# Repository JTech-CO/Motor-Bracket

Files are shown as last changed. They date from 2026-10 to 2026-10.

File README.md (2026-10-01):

# 스마트카트 모터 브래킷 · Rev G / 0.7.0

학교 프린터의 **200 × 200 × 200 mm** 상한에 맞춘 폭 축소 개정. 본체는 **196 × 162 × 180 mm**, 좌우 각각 별도의 단일 솔리드이며 분할 접합 없이 한 개씩 출력함.

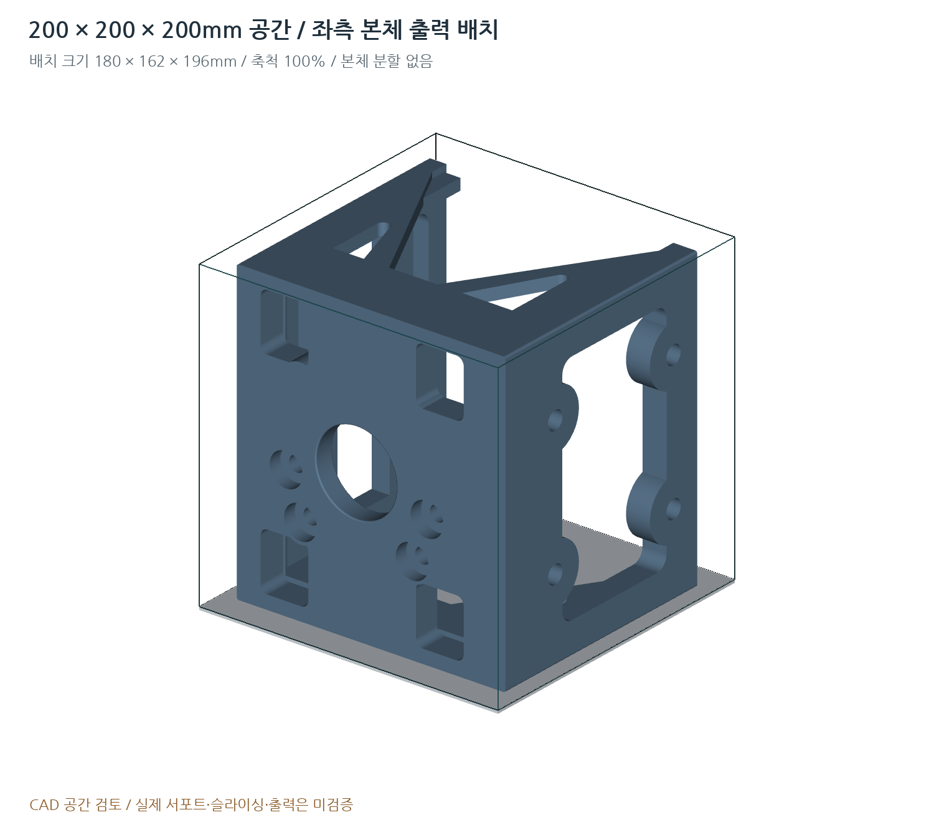
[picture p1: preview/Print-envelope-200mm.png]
200mm 출력 공간


## 우선 사용할 파일

- 출력: `print/bed_ready/SCMB-G01-L-BED.stl`, `SCMB-G01-R-BED.stl` — 각각 1개. 배치 크기 **180 × 162 × 196 mm**.
- 받침: 같은 폴더의 `SCMB-G03-L-BED.stl`, `SCMB-G03-R-BED.stl` — 각각 1개. **176 × 105 × 41.430 mm**.
- SolidWorks: `cad/step/SCMB-G01-L.step` / `SCMB-G01-R.step`. 받침은 G03, 금속 참고부 포함 조립은 G10.
- FreeCAD: `cad/freecad/`의 같은 이름 FCStd. 빈 화면이면 루트 `OPEN_IN_FREECAD.FCMacro`로 BREP를 직접 가져와 네이티브 재저장.
- 도면: [설계도면](drawings/설계도면.pdf), [수정설명서](docs/수정설명서.pdf), 1:1 모터/차체 템플릿.

## Rev F 대비 변경

| 항목 | Rev F | Rev G |
|---|---:|---:|
| 본체 크기 | 212 × 162 × 180 | **196 × 162 × 180 mm** |
| 외곽 좌우 끝 | ±106 | ±98 mm |
| 상·하판 경량화 창 폭 | 170 | 154 mm |
| 전면 창의 좌우 중심 | ±78 | ±70 mm |
| 받침 레일 바깥/안쪽 좌표 | ±96 / ±84 | ±88 / ±76 mm |
| 핀 중심 X | ±90 | ±82 mm |
| 전방 모서리 기둥 깊이 | 30 | 28 mm |

단순 전체 축소를 하지 않음. 상판 M8×40 4개, 측면 M6×30 4개, 차체 중심간격90×100, 출력축 위치, 모터 각도L -45° / R135°, 8인치 기준 명목 지상고21.6 mm를 유지함. 상판16 / 측판18 / 하판12 / 거싯8 mm와 루트R10도 유지함.

## 출력 공간

회전 배치 STL의 본체 영역은 X10~190 / Y19~181 / Z0~196 mm. 200 mm 배드 중심에 한 부품씩 배치함. 5 mm 외곽 브림을 가정한 공간은 **190 × 172 mm**, 높이는196 mm임. 이는 기하학적 영역 계산이며 실제 서포트·퍼지라인·스커트·래프트·툴패스 검증이 아님. 외부 서포트가 이를 넘을 수 있으므로 학교 슬라이서 프로필에서 확인함. 래프트/두꺼운 받침을 추가하면 Z=200 mm 제한을 다시 확인함.

**100% 크기(mm) / 사용자가 요청한 100% 채움 설정.** STL에는 채움률이 저장되지 않음. 축소하여 맞춤 기능은 사용하지 않음. 기본 방향 STL도 최대196 mm라 200 mm 큐브 안에 들어가지만, 배드 회전본은 X/Y에 브림 여유를 더 확보한 배치임. 층간하중과 서포트는 실제 재료·출력 방향으로 재검토해야 함.

## 질량과 기하 검사

기존 밀도1.06 g/cm³ 입력을 유지한 CAD 계산: 본체 **1.193 kg/개**, 받침 **0.113 kg/개**, 플라스틱 좌우 합계 **2.611 kg**. 금속부·모터·서포트·브림은 제외함. Rev F 약2.800 kg 대비 약0.189 kg 감소함.

대리 모터 캔과 본체의 최소 기하 간격 **1.699 mm**. 조립 및 연속200 mm 삽입 경로 검사 **165개**, 출력공간·고정치수·실제홀축 검사 **68개** 통과. 모든 출력용 본체/받침의 STEP·STL 최대 치수를 검사함. 결과는 `qa/`에 있음.

**DEMO 형상 무간섭이 실물 맞춤이나 하중 안전을 보장하지 않음.** 모터 자료5쪽의 D01 외경·E02 편심·L04 보스·M01 귀 두께 등은 실측 대기 상태임. 외곽 폭을 줄여 주변 여유가 작아졌으므로 실측 대조가 특히 중요함. 21.6 mm 지상고는 타이어 눌림·구조 변형·바닥 요철을 차감하기 전의 명목값임.

## CAD 및 구조 검증의 한계

FCStd는 외부에서 직렬화한 `Part::Feature` 정밀 솔리드. 완전 구속 스케치·피처 이력은 아님. 형상 입력 치수의 재생성 원본은 `parameters.json`과 `src/geometry.py`임. `.SLDPRT`/`.SLDASM`/Simulation 프로젝트를 생성하지 않음. STEP는 정밀 솔리드 가져오기/직접 편집의 시작 형상임.

FreeCAD·SolidWorks 앱의 실제 화면/열기 검사는 미실시. 기존 BREP 직접 가져오기 매크로와 AP214 대안을 유지함. 매크로 역시 문법 검사만 실시함. **Rev G 구조 FEA·실물 출력·하중시험 미실시.** 단면/레일 위치 변경으로 기존 개정의 응력·변위·안전율을 전용하지 않음.

## 재생성

```bash
python -m pip install -r requirements.txt
python src/export_package.py
python src/check_design.py
python src/check_print_envelope.py
python src/render_preview.py
python src/render_print_bed.py
python src/write_docs.py
python src/make_drawings.py
python src/verify_package.py
python src/finalize_package.py
```

문서 생성에는 로컬 한국어 TTF가 필요함. Windows 맑은 고딕/리눅스 나눔고딕 또는 `FONT_KR`·`FONT_KR_BOLD` 환경변수를 사용함. 폰트 파일은 배포하지 않음. 치수를 바꾸면 구형 생성파일을 혼용하지 않고 전체 재생성함. 내보내기는200 mm 초과 시 중단함.

참조PDF2개·PNG1개는 `reference/`에 원본 유지. 자료에서 확정되지 않은 길이를 추측해 실측값으로 바꾸지 않음. 기준 저장소 커밋: `4792da580a78f302c24412488b0d653e7083863d` (Rev F). 원격 GitHub는 이 패키지로 수정하지 않았음.

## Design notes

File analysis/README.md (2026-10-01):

# 구조해석 상태

Rev G(196 × 162 × 180 mm)는 구조 FEA 미실시임. Rev E의 수치 및 Rev F의 형상 검사를 본 개정의 안전율이나 강도 승인으로 사용하지 않음.

상판 16 / 측판 18 / 하판 12 / 거싯 8 / 루트 R10은 유지함. 폭, 전면 창 위치, 측면 기둥 깊이, 레일과 잠금핀 위치를 변경했으므로 실제 접촉·적층 이방성·볼트 예압·크리프·열 조건을 넣어 새 형상으로 재해석해야 함.

해석용 시작 형상은 cad/step/SCMB-G10-L.step 및 R.step의 분리 솔리드 조립임. 모터 대리형상은 제작 대상이 아니며 모터 본체의 질량/출력축 하중 조건을 별도로 설정함. `src/geometry.py`의 bonded_analysis는 완전결합 비교체를 만드는 함수로 실제 접촉모형을 대체하지 않음.

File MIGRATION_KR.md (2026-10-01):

# Rev F → Rev G 교체 안내

원격 저장소의 .git 디렉터리와 사용자 변경을 보존하고 별도 브랜치 또는 백업에서 교체함. 자동 삭제·git push는 이 패키지에서 실행하지 않음.

이 패키지는 전체 생성본임. 이전 `cad/`, `compatibility/`, `drawings/`, `print/`, `preview/`, `qa/`의 Rev F 출력 파일은 새 파일과 함께 발주/출력 목록에 남기지 않음. Git의 변경 목록에서 `SCMB-F*`가 제거되고 `SCMB-G*`로 바뀌는지 검토함. `parameters.json`, `src/`, 루트 매크로/안내/검사파일과 data/도 함께 교체함.

각 본체 폭196 mm, 각 받침 폭176 mm. 체결용 M8·M6의 수와 길이 및 차체 피치는 같지만 레일과 핀 위치가8 mm 이동했으므로 **Rev F 받침과 Rev G 본체를 혼합하지 않음**. 좌우 표기도 유지함. 모터·바퀴가 포함된 검토 조립 STEP는 출력 대상이 아님.

배포 후 `python CHECK_FILES.py`로 로컬 파일 손상 여부를 점검함. 이는 실제 CAD 앱 화면 검사와 별개임.

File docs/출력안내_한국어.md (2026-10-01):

# 200 mm 프린터 출력 안내

`print/bed_ready`의 L/R 본체 및 L/R 받침을 각각1개씩, 한 번에 한 부품으로 출력함. 본체 BED STL은 측면을 아래로 회전 배치하여180×162×196 mm임. 바닥 좌표는Z=0이며 mm/축척100%를 사용함. 원본 방향 STL은196×162×180 mm임.

명목200 mm 큐브 안에 들어가는 형상 검사를 완료했으나 기종·노즐·재료 설정이 미제공이라 실제 슬라이싱은 미실시임. 5 mm 브림을 더한 본체 외접영역190×172 mm는 계산 예시이며 실제 접착력 보장이나 권장 브림 폭 확정이 아님. 서포트, 스커트, 퍼지, 클립, 래프트의 최종 툴패스를 포함해200 mm를 넘는지 확인함. 최종Z높이도200 mm 이하여야 함.

100% 채움은 슬라이서에서 지정함. 출력품의 물성은 적층방향과 실제 공정에 달려 있으므로 100% 채움만으로 강도 승인이 되지 않음. 학교장비가 선택한재료에 필요한 노즐·챔버·건조 조건을 제공하는지 확인함. 끼워맞춤·홀·레일은 작은 시험편 또는 해당 단면 선행 출력으로 보정 후 본체를 출력함.

M8용 금속 압축제한슬리브와 M6용 금속 압축제한슬리브, 잠금핀은 플라스틱으로 대체 출력하지 않음. reference나 모터대리형상은 제작대상이 아님. 모터 맞춤은 실측해야하며 체결 토크와 실물 운행 하중은 아직 승인하지 않음.

외부 참고: Prusa의 Skirt and Brim 문서는 브림이 첫 레이어 접착면적을 늘리며 폭을 별도로 설정하는 기능임을 설명함. 특정 학교 장비에 대한 프로필은 아님. https://help.prusa3d.com/article/skirt-and-brim_133969

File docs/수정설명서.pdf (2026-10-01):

SCMB Rev G / 200mm 공간 검토본 / 실물·구조 승인 전 | 1

# Rev G / 200mm 프린터 대응 수정

스마트카트 모터 브래킷 · 0.7.0 · 2026-10-01
좌우 단일 본체196×162×180mm / 기능 치수 유지 / 제작 검토본

### 1. 전체 비율이 아닌 외곽 폭만 줄임

학교 프린터 상한200×200×200mm를 기준으로 외곽 폭212mm를196mm로 조정했다. 각 본체를 별도 파트로 분할하지 않는다. 전체 모델을196/212 비율로 축소하지 않고 측면 구조와 경량화 창·받침 레일을 국소적으로 이동했다.

항목 | Rev F | Rev G
본체 외곽(mm) | 212×162×180 | 196×162×180
레일 전체 폭(mm) | 192 | 176
핀 중심X(mm) | ±90 | ±82
상·하판 창 폭(mm) | 170 | 154
전방 기둥 깊이(mm) | 30 | 28

상판16 / 측판18 / 하판12 / 거싯8mm와 루트R10을 유지했다. 앞쪽 기둥 두께12mm도 유지하고 깊이를 2mm 줄여 대리 모터의 Y=30 앞끝과의 공간을 확보했다. 이번 국소 변경이 강도 유지의 검증을 의미하지 는 않는다.

기존 밀도1.06g/cm³를 그대로 사용한 CAD 플라스틱 질량은 좌우 합계 2.611kg이다. Rev F 약2.800kg 대비 약0.189kg 감소했다. 모터·금속부·서포트·브림·출력 오차를 제외한다.

기준 저장소: JTech-CO/Motor-Bracket, 커밋4792da580a78f302c24412488b0d653e7083863d의 Rev F. geometry.py의 Git blob SHA를 대조한 후 소스를 수정했다. 원격 저장소 수정이나 발주는 하지 않 았다.

# 2. 출력 배치와 슬라이서 설정

출력 파일 | 배치 크기(mm) | 수량
SCMB-G01-L-BED.stl | 180×162×196 | 1
SCMB-G01-R-BED.stl | 180×162×196 | 1
SCMB-G03-L-BED.stl | 176×105×41.430 | 1
SCMB-G03-R-BED.stl | 176×105×41.430 | 1

print/bed_ready의 본체 파일은 측면을 바닥으로 +Y축90° 회전하고 XY 중앙·Z0으로 옮긴 STL이다. 축척 은100%이며 스케일 변경이 아니다. 원래 방향 STL도196×162×180mm로200mm 큐브 안에 들어간다.

본체 배치 좌표는 X10~190 / Y19~181 / Z0~196mm이다. 5mm 브림을 가정하면 외접영역은 190×172mm이고 높이는196mm로 유지된다. 이는 브림의 기하 공간 계산이며 학교 장비의 실제 G-code 는 생성하지 않았다.

### 실제 출력 전에 확인

한 작업에 본체 한 개씩 배치하고 mm·축척100%·내부채움100%를 사용한다. STL에는 채움률이 저장되 지 않는다. 받침은 별도 작업이다. 모터·바퀴·금속부가 들어간 검토조립 STEP는 출력대상이 아니다.

슬라이서에서 서포트·브림·스커트·퍼지·래프트를 포함한 최종 툴패스가200mm 공간 안인지 확인한다. 학 교 기종·클립 위치·제한구역·노즐·재료 프로필이 없어 실제 슬라이싱은 미검증이다. 래프트나 높이 보정을 추가하면 남은Z여유4mm를 초과하지 않는지 확인한다.

측면 출력 방향은 공간 적합성을 위한 배치다. 층간강도와 서포트 접촉을 검토한 출력조건을 사용한다. 5mm 브림을 접착력 확정값으로 취급하지 않는다. 장비가 재료의 건조·노즐·챔버 조건을 충족하는지도 확 인한다.

브림 참고: Prusa 공식 “Skirt and Brim”은 첫 레이어의 접착면적을 늘리며 폭을 따로 지정하는 기능으로 설 명한다. 이 설명은 학교 프린터 전용 설정을 제공하는 것은 아니다. 주소는data/sources.json에 있다.

# 3. 바퀴·체결 및 CAD 파일

유지 항목 | Rev G 값
차체 체결 | M8×40mm 4개 / 중심 간격90×100mm
모터 체결 | M6×30mm 4개 / 원본 공급원 패턴의 회전 좌표 유지
출력축 중심 | 좌우 동일 높이Z0 / 중앙 여유홀Ø54와 동심
하판 최하단 / 상판면 | Z=-80 / Z=+100mm
8인치 명목 지상고 | 203.2/2 - 80 = 21.6mm
모터 상대 각도 | L -45° / R135° / 차이180°

Ø54 개구는 축을 지지하는 베어링홀이 아니다. 바퀴허브·모터베어링 하중과 축물림은 별도 확인해야 한다. 21.6mm는 무하중 명목값으로 타이어 눌림과 구조 변형이 차감되기 전이다.

브래킷 M8/M6 자리는 각각 Ø12.2/Ø10.2 슬리브 수용홀이다. 금속 슬리브 ID는Ø9.0/Ø6.6이다. 볼트 유 효 두께12/9mm를 유지했으나 모터 귀와 잠금너트·와셔 실측이 없으므로 M6×30의 길이 적합성과 체결토 크는 확정 전이다.

### FreeCAD와 SolidWorks

cad/step은 각각 유효한 단일 솔리드 AP203을 제공한다. 대안 AP214는compatibility/AP214에 있다. SolidWorks는STEP를 가져와 직접 편집하거나 새 피처/해석을 추가하는 시작형상으로 사용한다. 고유 SLDPRT/SLDASM/Simulation 프로젝트는 제공하지 않는다.

cad/freecad의 FCStd는 외부 직렬화한 Part::Feature 솔리드 문서이며 원시 스케치 이력이 아니다. 빈 화 면이면 OPEN_IN_FREECAD.FCMacro로BREP를 직접 읽어 표시·네이티브 저장·재열기를 수행한다. 실제 앱 버전/결과는native_generated/app_report.json에 기록된다. 여기서는 앱/매크로 실행은 하지 않았다.

parameters.json·src/geometry.py가 재생성 원본이다. 전용 출력 한계 검사로200mm 초과 시 내보내기 를 중단한다. 기존Rev F 본체/받침과 새Rev G를 혼용하지 않는다.

# 4. 검증 결과와 제작 승인 조건

검사 항목 | 실행 결과
기하·연속200mm 삽입 경로 | 165개 통과 / 명시된 대리형상 기준
출력공간·실제 홀축·회전배치 | 68개 통과 / STEP·STL200mm 이내
STEP / FCStd | AP203·AP214 재읽기 / FCStd ZIP·XML·내장BREP 검사
학교 장비 슬라이싱·출력 | 미실시 / 실제 프로필·툴패스 미제공
CAD 앱 직접 실행 | FreeCAD·SolidWorks 및 매크로 실행 미실시
새 형상 구조해석·하중시험 | 미실시 / 기존 개정의 응력·안전율 전용 금지

모터 캔 대리형상과 본체의 최소 거리는 약1.699mm다. 실제 모터 크기·도장·편심·배선이 다르면 달라진다. 0체적 간섭 및 양의 공차 여유는 실물 끼워맞춤 승인이 아니다.

첨부 모터자료의 5쪽은 D01 몸통 외경, E02 편심, L04 보스, M01 귀 두께와 접촉평면 등을 실측란으로 남 긴다. 공급원Ø102·Ø17과4개 장착홀 좌표는 실측 공차 승인값이 아니다. 본 개정에서 외부 모터치수를 임 의로 확정하지 않았다.

지지대 두께는 유지했지만 폭·레일·보강기둥 위치를 바꾸었으므로 구조 검증은 새 형상으로 수행한다. 실제 접촉, 적층이방성, 볼트 예압, 금속 슬리브, 크리프와 온도를 고려한다. 사람 탑승이나 고속 운행에 대한 승 인을 포함하지 않는다.

참조PDF2개 및PNG1개는 reference/에 원본 그대로 보존했다. 다운로드 무결성은CHECK_FILES.py로 점 검한다. 수치 결과는qa/와data/print_parts.csv에서 볼 수 있다. 한국어 README에 전체 재생성 순서가 있다.

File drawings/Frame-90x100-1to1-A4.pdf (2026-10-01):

# 차체 90×100mm / 홀 중심 대조 1:1

SCMB / Rev G · 0.7.0 / 2026-10-01 / mm / 장착·구조·앱별 최종 승인 전

검토용 · 도면의 미실측 대리값을 제조 확정값으로 사용하지 말 것 | 1 / 1

90mm

100mm

실선 Ø12.2: 상판 슬리브 수용홀 / 점선 Ø24: 와셔 외경 예시. 실제 차체 장공의 최종 볼트 착좌점을 대조한다. 본체196×162mm 외곽은 이 홀 중심 대조도에 표시하지 않는다.

100mm 출력 교정선

인쇄 100% · 페이지 맞춤 끄기 · 교정선을 실제 자로 확인

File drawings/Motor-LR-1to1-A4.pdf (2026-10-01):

# L / 모터 홀 중심 대조용 1:1

SCMB / Rev G · 0.7.0 / 2026-10-01 / mm / 장착·구조·앱별 최종 승인 전

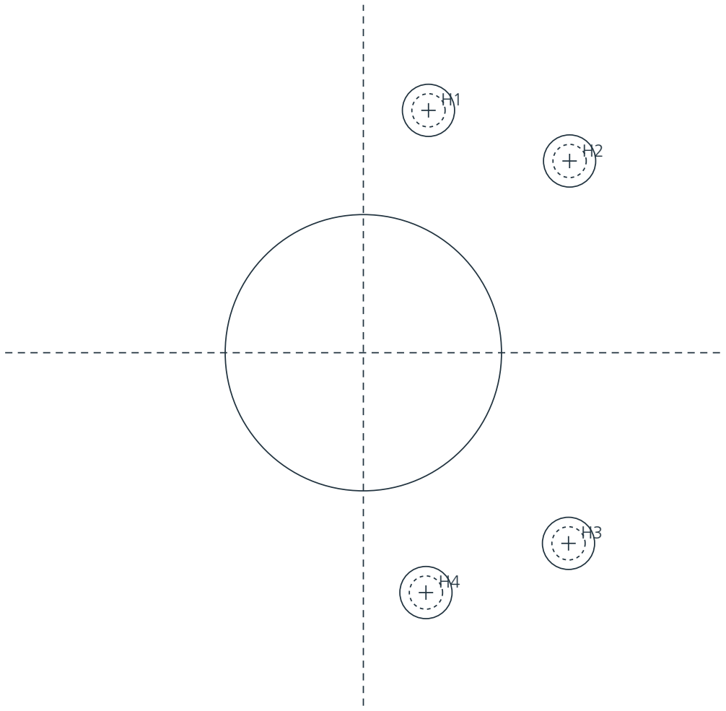
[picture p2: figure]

검토용 · 도면의 미실측 대리값을 제조 확정값으로 사용하지 말 것 | 1 / 2

실선 Ø10.2: 브래킷 슬리브 수용홀 / 점선 Ø6.5: 공급원 모터 귀 구멍. 현재 각도는 대리 편심 기준이다. 실제 모 터에 맞추어 회전/접촉면을 먼저 대조한다.

100mm 출력 교정선

인쇄 100% · 페이지 맞춤 끄기 · 교정선을 실제 자로 확인

# R / 모터 홀 중심 대조용 1:1

SCMB / Rev G · 0.7.0 / 2026-10-01 / mm / 장착·구조·앱별 최종 승인 전

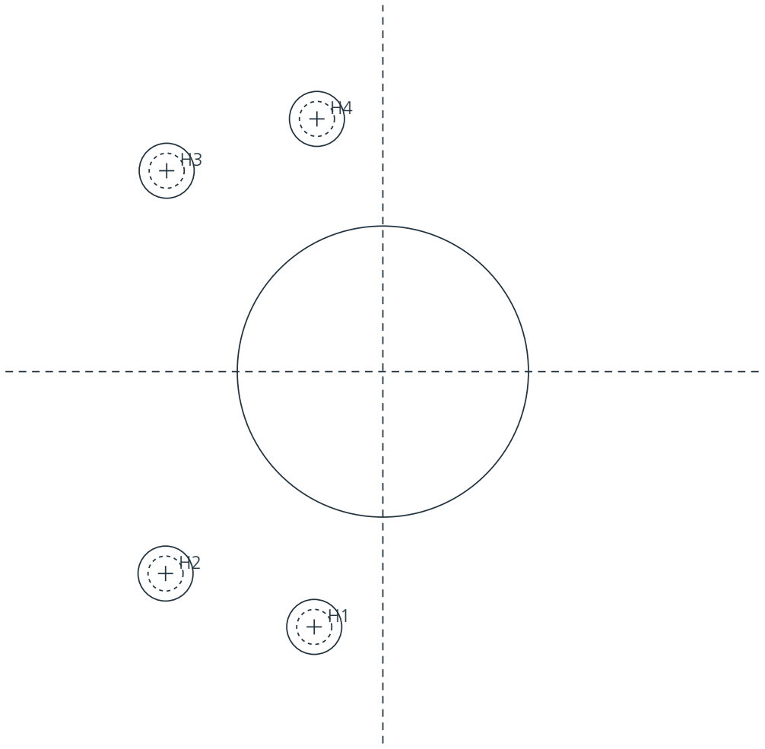
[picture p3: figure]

검토용 · 도면의 미실측 대리값을 제조 확정값으로 사용하지 말 것 | 2 / 2

실선 Ø10.2: 브래킷 슬리브 수용홀 / 점선 Ø6.5: 공급원 모터 귀 구멍. 현재 각도는 대리 편심 기준이다. 실제 모 터에 맞추어 회전/접촉면을 먼저 대조한다.

100mm 출력 교정선

인쇄 100% · 페이지 맞춤 끄기 · 교정선을 실제 자로 확인

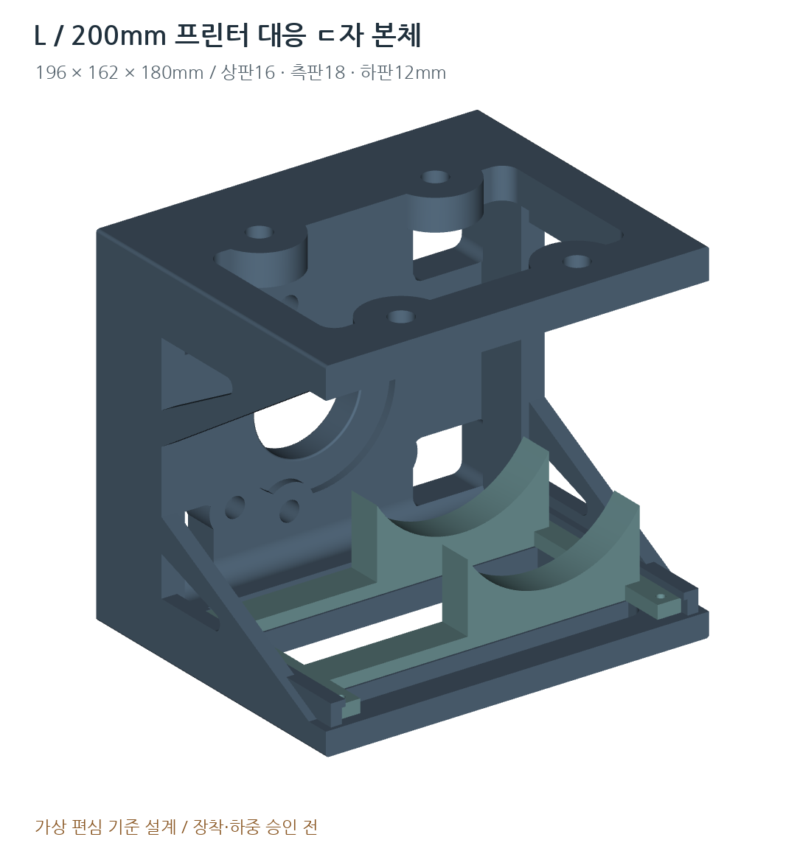
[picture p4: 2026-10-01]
preview/L-Bracket.png

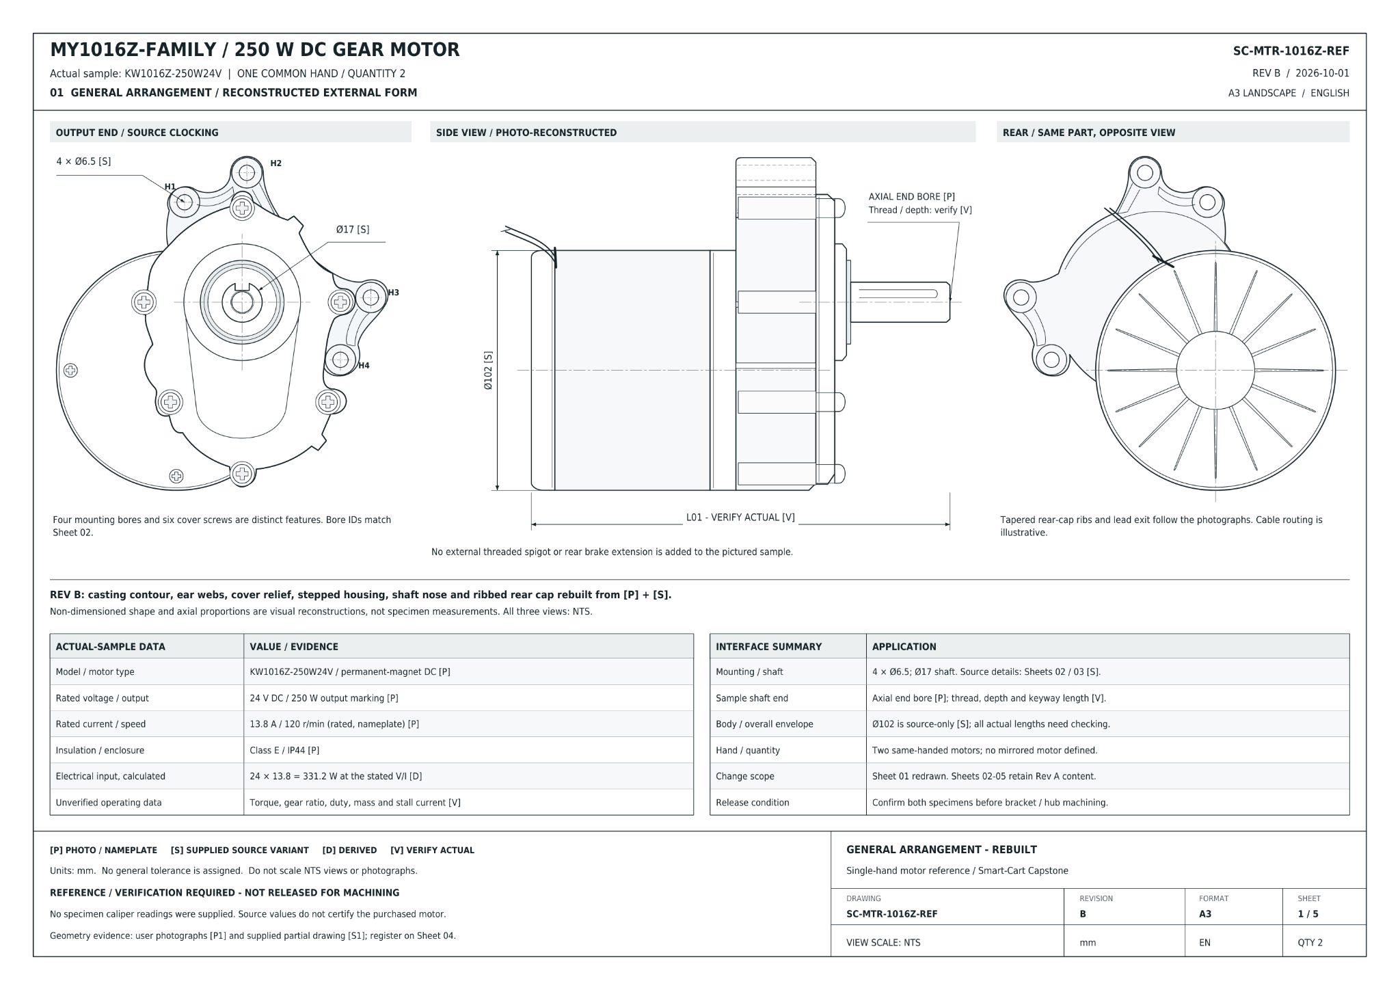
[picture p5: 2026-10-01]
reference/MY1016Z Detailed Reference Image.png

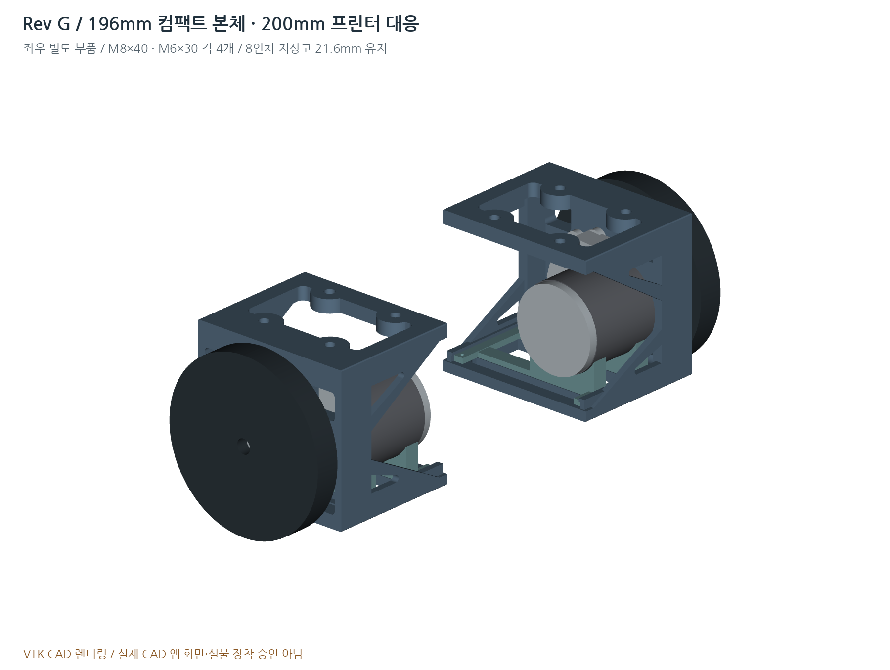
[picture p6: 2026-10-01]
preview/SCMB-RevG-8inch.png

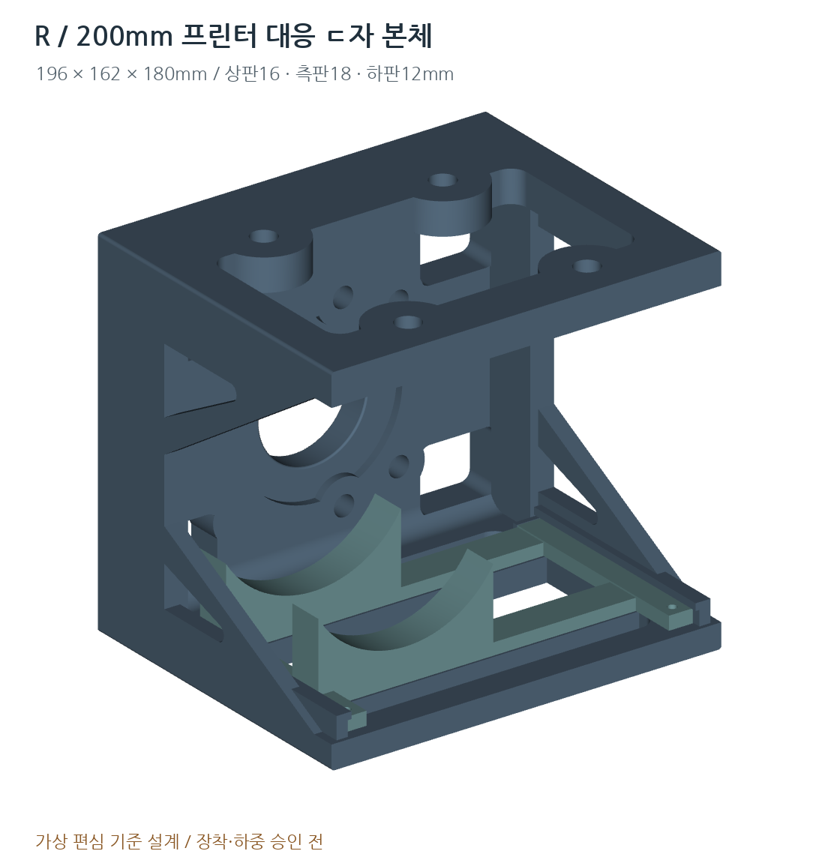
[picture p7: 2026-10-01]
preview/R-Bracket.png

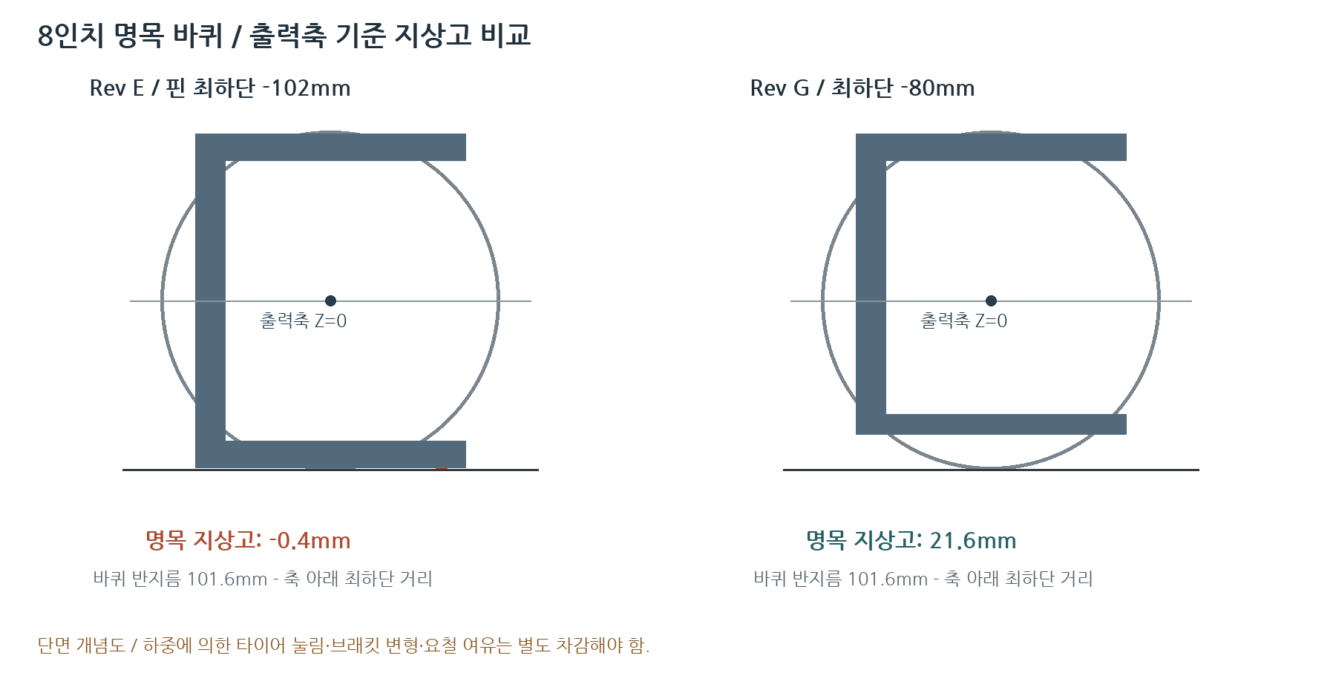
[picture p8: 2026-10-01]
preview/Ground-clearance.png

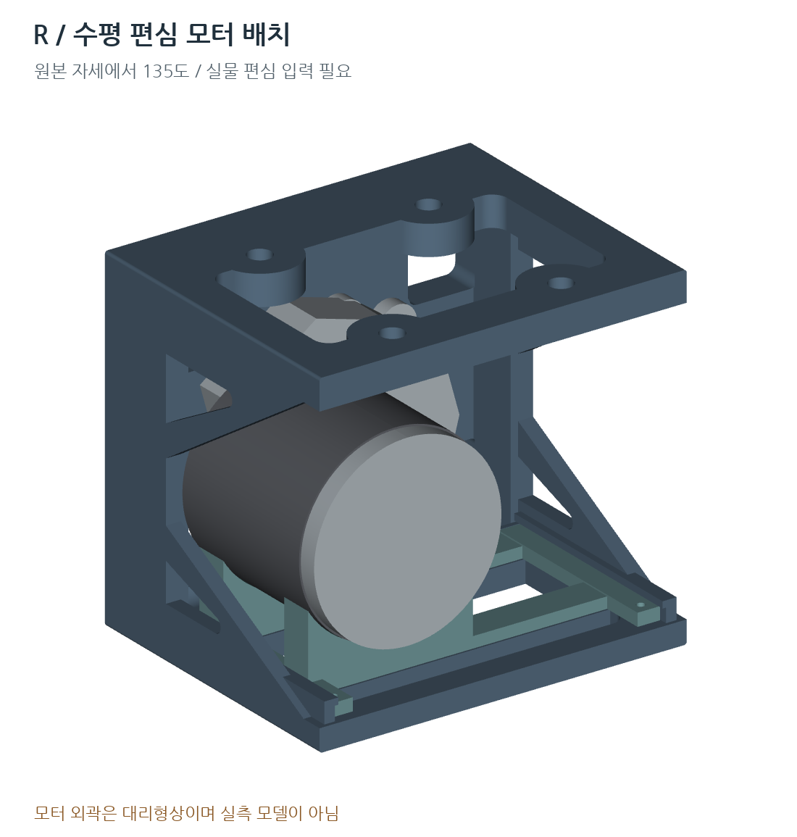
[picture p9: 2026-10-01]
preview/R-Motor.png

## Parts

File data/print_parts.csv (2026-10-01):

부품 | STL파일 | 출력배치Xmm | 출력배치Ymm | 출력배치Zmm | 수량 | 축척 | 채움요청% | 주의
SCMB-G01-L | print/bed_ready/SCMB-G01-L-BED.stl | 180.0 | 162.0 | 196.0 | 1 | 100% | 100 | 한 부품씩 출력 / 서포트·프린터프로필 검토
SCMB-G03-L | print/bed_ready/SCMB-G03-L-BED.stl | 176.0 | 105.0 | 41.43 | 1 | 100% | 100 | 한 부품씩 출력 / 서포트·프린터프로필 검토
SCMB-G01-R | print/bed_ready/SCMB-G01-R-BED.stl | 180.0 | 162.0 | 196.0 | 1 | 100% | 100 | 한 부품씩 출력 / 서포트·프린터프로필 검토
SCMB-G03-R | print/bed_ready/SCMB-G03-R-BED.stl | 176.0 | 105.0 | 41.43 | 1 | 100% | 100 | 한 부품씩 출력 / 서포트·프린터프로필 검토

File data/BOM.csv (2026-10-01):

부품 | 규격 | 양쪽합계 | 상태
좌측 본체 | SCMB-G01-L | 1 | 실측 및 구조 검증 전
우측 본체 | SCMB-G01-R | 1 | 실측 및 구조 검증 전
좌측 받침 | SCMB-G03-L | 1 | 실측 및 구조 검증 전
우측 받침 | SCMB-G03-R | 1 | 실측 및 구조 검증 전
차체 볼트 | M8x40 | 8 | 사용자 규격 / 피치·등급 확인
모터 볼트 | M6x30 | 8 | 사용자 규격 / 귀 두께로 길이 확인
M8 슬리브 | OD12 / ID9 / L11.9 예시 | 8 | 금속 / 실제 길이 확정 전
M6 슬리브 | OD10 / ID6.6 / L8.9 예시 | 8 | 금속 / 실제 길이 확정 전
M8 와셔 | OD24 / t2 예시 | 16 | 차체 장공 받침 검토
M6 와셔 | OD18 / t1.6 예시 | 16 | 모터 접근 검토
M8 잠금너트 | 실제 높이 확인 | 8 | 공급품 확인
M6 잠금너트 | 실제 높이 확인 | 8 | 공급품 확인
금속 잠금핀 | D4 / L24 / 머리2 예시 | 4 | 공급품 규격과 R클립 확인
핀 이탈방지 클립 | 잠금핀에 적합 | 4 | 공급품 확인

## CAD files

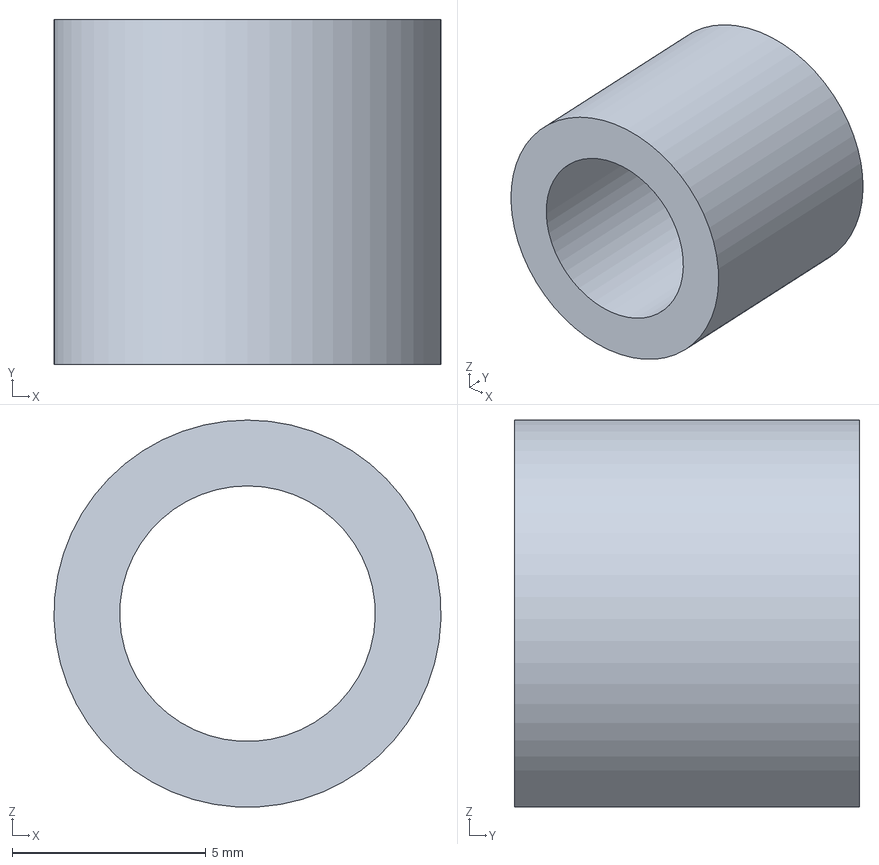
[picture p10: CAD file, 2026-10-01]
cad/step/SCMB-G02-M6.step
10.00 x 8.90 x 9.99 mm

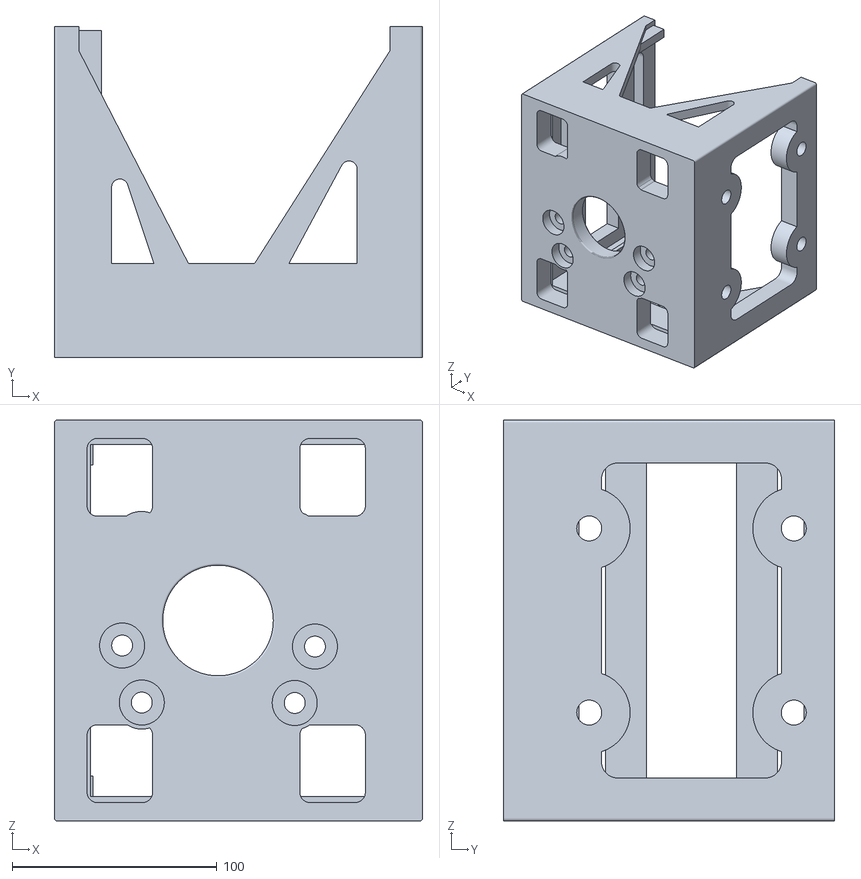
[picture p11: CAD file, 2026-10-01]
print/bed_ready/SCMB-G01-L-BED.stl
180.0 x 162.0 x 196.0

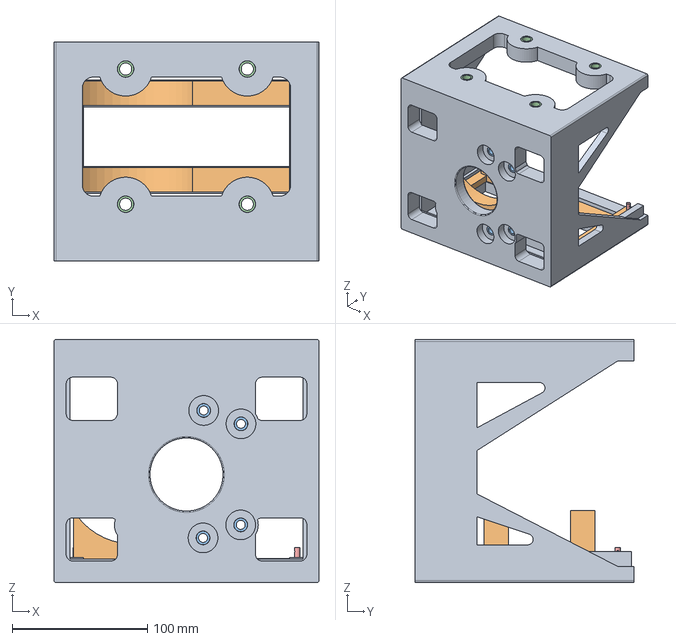
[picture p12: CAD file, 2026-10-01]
cad/step/SCMB-G10-L.step
196.0 x 162.0 x 180.0 mm

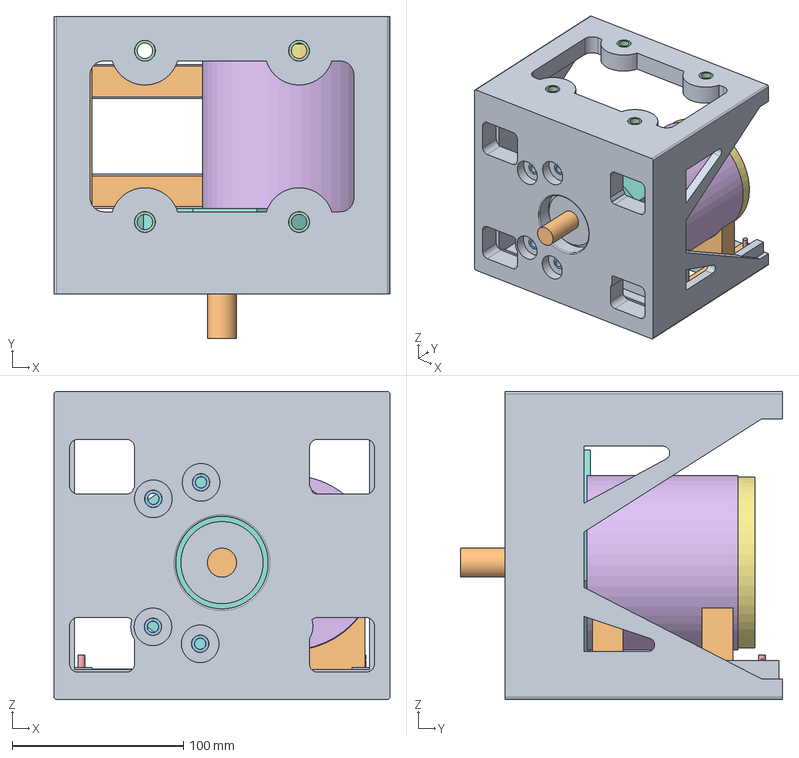
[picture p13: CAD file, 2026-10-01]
compatibility/AP214/SCMB-G20-R-MOTOR-DEMO.step
196.0 x 188.0 x 180.0 mm

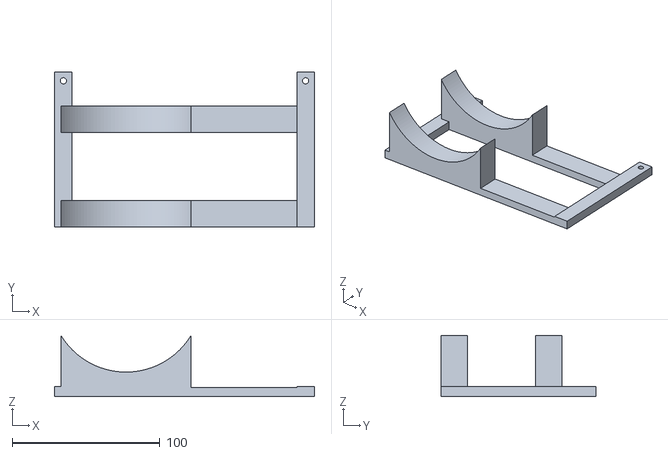
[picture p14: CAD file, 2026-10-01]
print/bed_ready/SCMB-G03-L-BED.stl
176.0 x 105.0 x 41.4

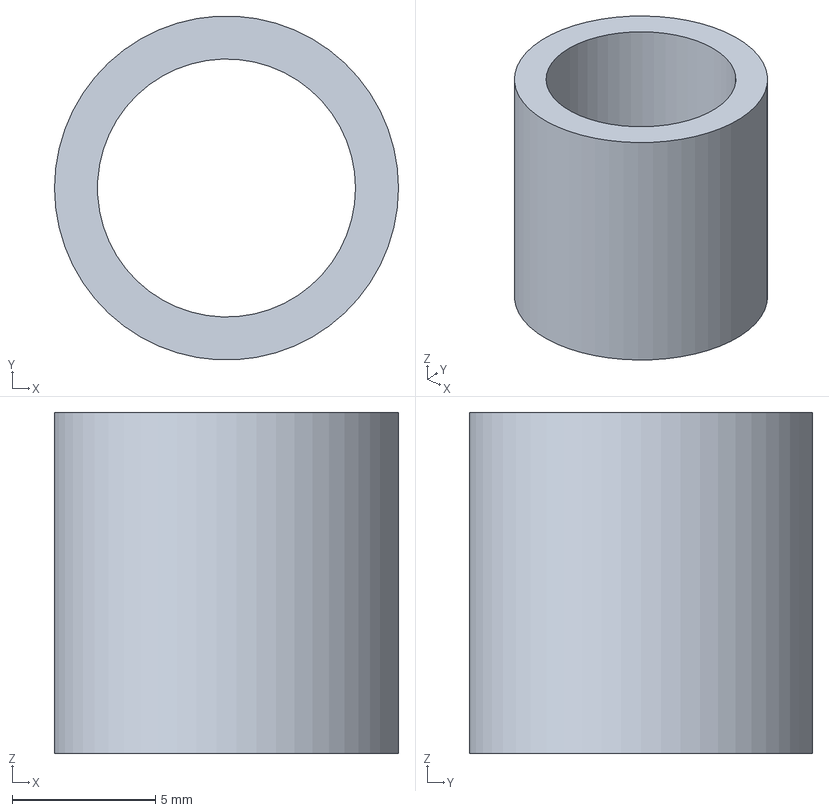
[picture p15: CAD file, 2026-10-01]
compatibility/AP214/SCMB-G02-M8.step
12.0 x 12.0 x 11.9 mm

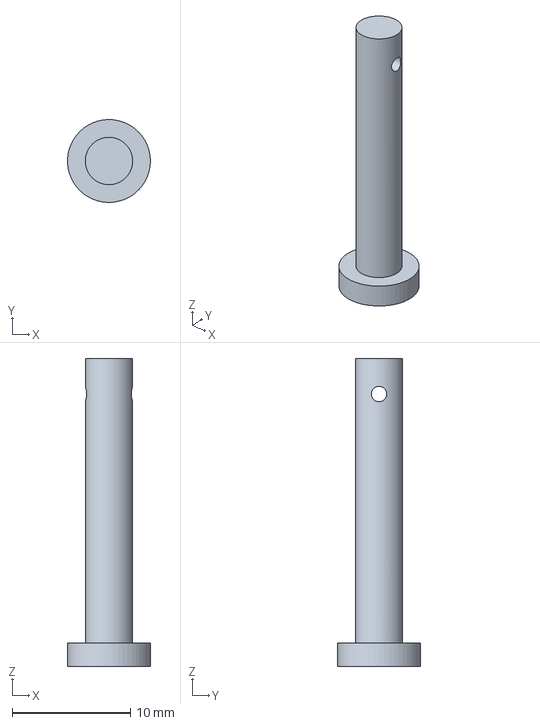
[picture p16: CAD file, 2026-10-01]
cad/step/SCMB-G05-PIN.step
6.99 x 7.00 x 26.0 mm

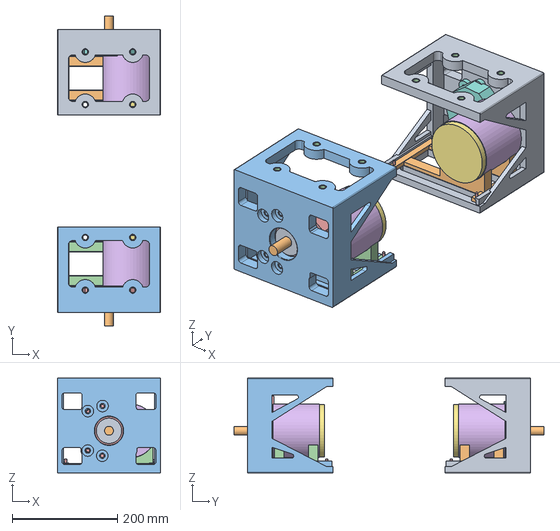
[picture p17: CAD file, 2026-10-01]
compatibility/AP214/SCMB-G00-PAIR-DEMO.step
196.0 x 588.0 x 180.0 mm

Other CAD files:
compatibility/AP214/SCMB-G02-M6.step
cad/step/SCMB-G20-L-MOTOR-DEMO.step
print/bed_ready/SCMB-G01-R-BED.stl
print/bed_ready/SCMB-G03-R-BED.stl
cad/step/SCMB-G10-R.step
compatibility/AP214/SCMB-G03-L.step
cad/step/SCMB-G03-R.step
compatibility/AP214/SCMB-G05-PIN.step
cad/step/SCMB-G00-PAIR-DEMO.step
compatibility/AP214/SCMB-G01-L.step
cad/freecad/00-CAD-TEST-CUBE.FCStd
cad/freecad/SCMB-G00-PAIR-DEMO.FCStd
cad/freecad/SCMB-G01-L.FCStd
cad/freecad/SCMB-G01-R.FCStd
cad/freecad/SCMB-G02-M6.FCStd
cad/freecad/SCMB-G02-M8.FCStd
cad/freecad/SCMB-G03-L.FCStd
cad/freecad/SCMB-G03-R.FCStd
cad/freecad/SCMB-G05-PIN.FCStd
cad/freecad/SCMB-G10-L.FCStd
cad/freecad/SCMB-G10-R.FCStd
cad/freecad/SCMB-G20-L-MOTOR-DEMO.FCStd
cad/freecad/SCMB-G20-R-MOTOR-DEMO.FCStd
cad/step/00-CAD-TEST-CUBE.step
cad/step/SCMB-G01-L.step
cad/step/SCMB-G01-R.step
cad/step/SCMB-G02-M8.step
cad/step/SCMB-G03-L.step
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

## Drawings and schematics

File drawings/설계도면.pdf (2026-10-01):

# 01 / 좌우 단일 본체 · 200mm 프린터 대응

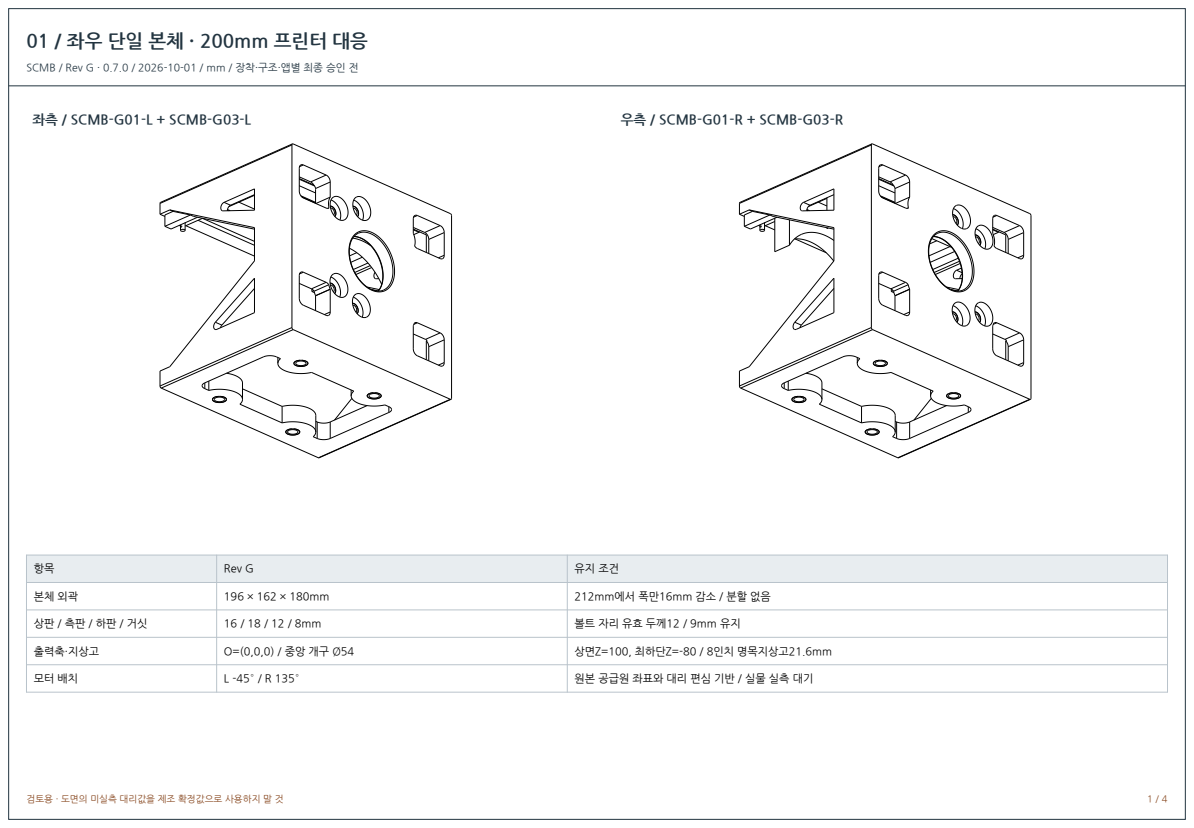
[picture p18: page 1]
검토용 · 도면의 미실측 대리값을 제조 확정값으로 사용하지 말 것; 좌측 / SCMB-G01-L + SCMB-G03-L; 우측 / SCMB-G01-R + SCMB-G03-R

SCMB / Rev G · 0.7.0 / 2026-10-01 / mm / 장착·구조·앱별 최종 승인 전

항목 | Rev G | 유지 조건

본체 외곽 | 196 × 162 × 180mm | 212mm에서 폭만16mm 감소 / 분할 없음

출력축·지상고 | O=(0,0,0) / 중앙 개구 Ø54 | 상면Z=100, 최하단Z=-80 / 8인치 명목지상고21.6mm

모터 배치 | L -45° / R 135° | 원본 공급원 좌표와 대리 편심 기반 / 실물 실측 대기

# 02 / 실제 출력 배치와 부품별 크기

SCMB / Rev G · 0.7.0 / 2026-10-01 / mm / 장착·구조·앱별 최종 승인 전


항목 | 공간 (mm)
학교 프린터 상한 | 200 × 200 × 200
본체 원래 방향 | 196 × 162 × 180
본체 회전 출력 배치 | 180 × 162 × 196
5mm 브림 외접영역 예시 | 190 × 172 / 높이196
받침 별도 출력 | 176 × 105 × 41.430
출력 위치 / 축척 | XY 배드 중앙 / Z=0 / 100%

본체 BED STL의 좌표: X10~190 / Y19~181 / Z0~196mm. 한 번에 한 개씩 출력. 5mm 브림은 영역 계산 예시이며 실제 접착 조건은 학교 장비·재료 프로필로 결정한다.

서포트·스커트·퍼지라인·래프트를 포함한 최종 툴패스는 미검증이다. 출력물 형상이200mm 이내라 는 사실과 실제 슬라이싱 완료는 다르다. 전체 축소로 공간을 맞추면 M8/M6 홀과 모터 맞춤이 바 뀌므로 금지한다.

측면으로 눕힌 배치는 체적 적합성을 위한 방향이다. 층간강도·서포트는 별도로 검토한다. 출력품 내부100% 채움은 슬라이서에서 설정한다.

# 03 / 모터 홀과 차체 체결 규격 유지

SCMB / Rev G · 0.7.0 / 2026-10-01 / mm / 장착·구조·앱별 최종 승인 전

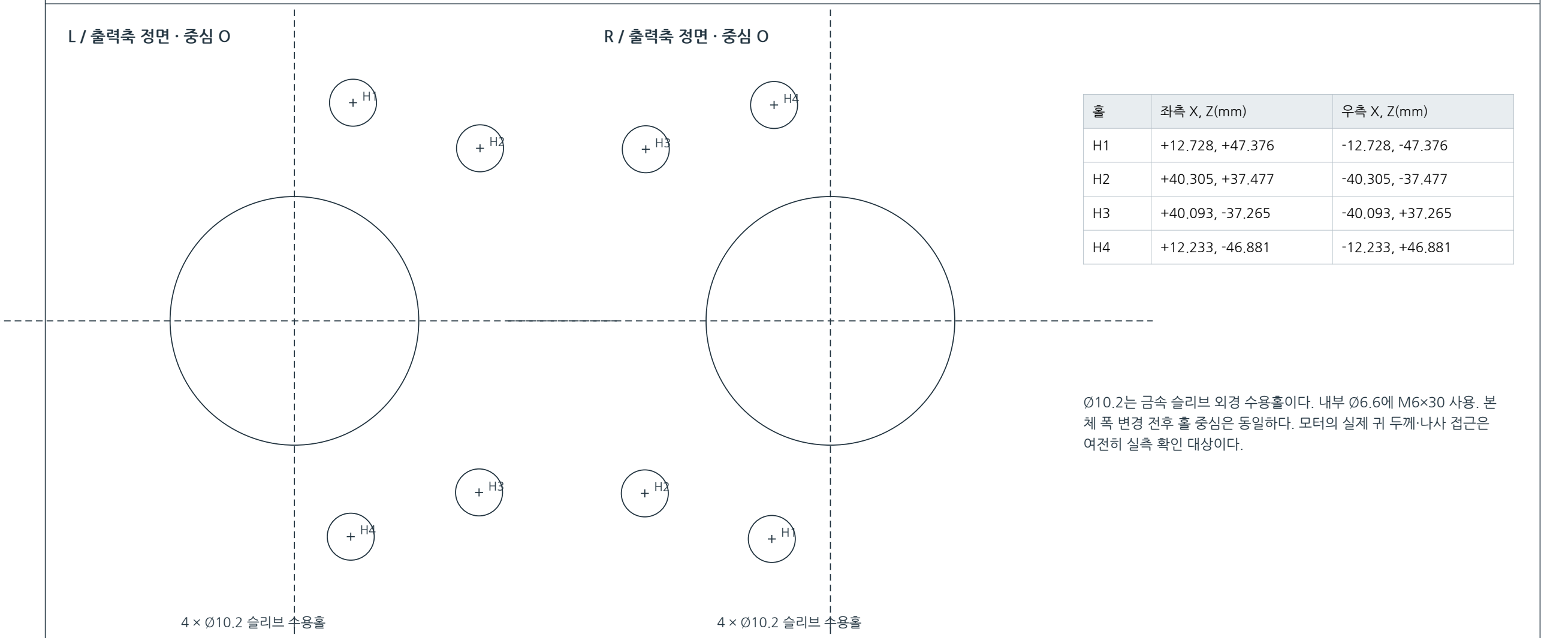
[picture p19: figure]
L / 출력축 정면 · 중심 O; 4 × Ø10.2 슬리브 수용홀; R / 출력축 정면 · 중심 O; 여전히 실측 확인 대상이다.

Ø10.2는 금속 슬리브 외경 수용홀이다. 내부 Ø6.6에 M6×30 사용. 본 체 폭 변경 전후 홀 중심은 동일하다. 모터의 실제 귀 두께·나사 접근은

체결 | 본체 수용홀 / 금속부 | 규격
차체 상판 | 4 × Ø12.2 / 슬리브 ID Ø9.0 | M8×40 4개 / 중심 간격90×100mm
모터 측판 | 4 × Ø10.2 / 슬리브 ID Ø6.6 | M6×30 4개 / 유효 두께9mm
잠금핀 | 2 × Ø4.2 / 머리 포켓 Ø7.6 × 2.2 | X=±82, Y=132 / D4 무나사핀2개/측

# 04 / 상면·측면 및 국소 폭 변경

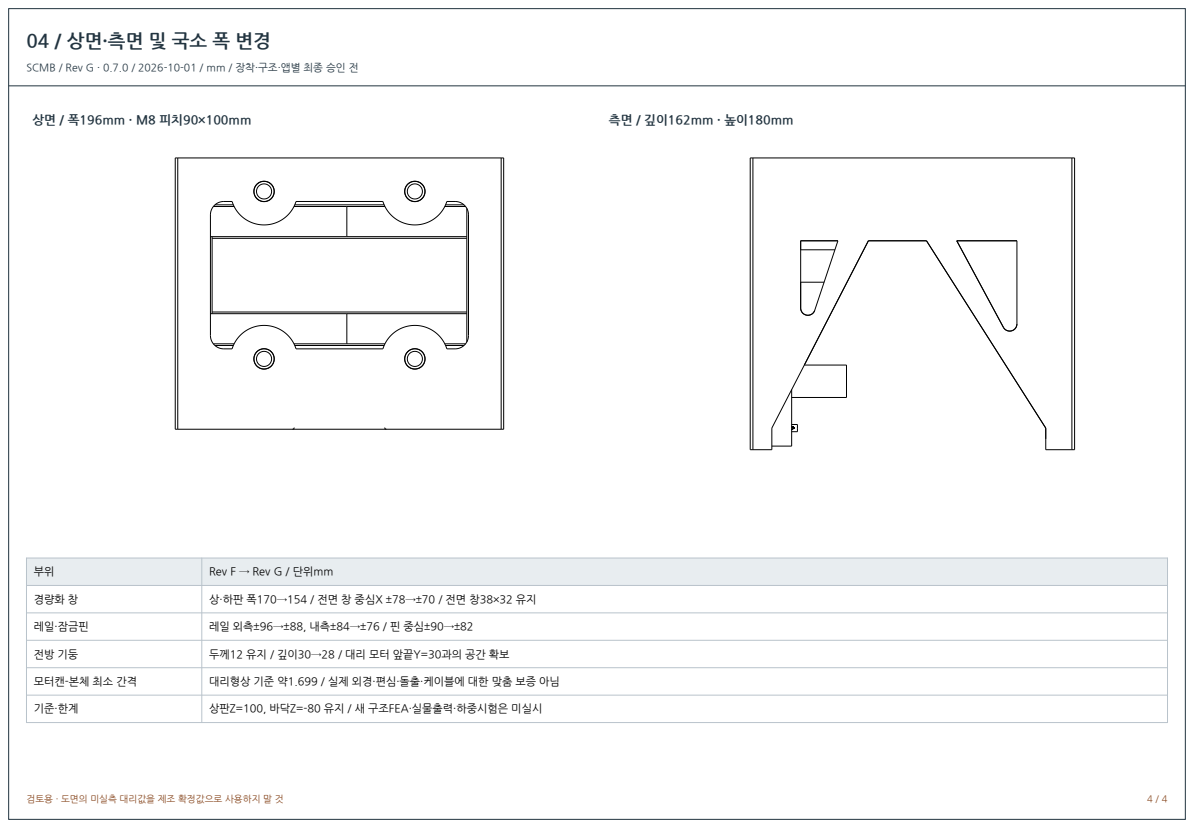
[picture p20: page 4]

SCMB / Rev G · 0.7.0 / 2026-10-01 / mm / 장착·구조·앱별 최종 승인 전

부위 | Rev F → Rev G / 단위mm

경량화 창 | 상·하판 폭170→154 / 전면 창 중심X ±78→±70 / 전면 창38×32 유지

레일·잠금핀 | 레일 외측±96→±88, 내측±84→±76 / 핀 중심±90→±82

전방 기둥 | 두께12 유지 / 깊이30→28 / 대리 모터 앞끝Y=30과의 공간 확보

모터캔-본체 최소 간격 | 대리형상 기준 약1.699 / 실제 외경·편심·돌출·케이블에 대한 맞춤 보증 아님

기준·한계 | 상판Z=100, 바닥Z=-80 유지 / 새 구조FEA·실물출력·하중시험은 미실시

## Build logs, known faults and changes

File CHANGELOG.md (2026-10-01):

# 개정 이력

## 0.7.0 / Rev G / 2026-10-01

200 mm 학교 프린터 제한 반영. 본체 폭212→196 mm; 모든 출력 대상 부품 최대치수200 mm 이하 검사. 전체 형상 비율 축소 없이 기능 치수 유지. 상·하판 창, 전면 창 위치, 레일과 핀을 안쪽8 mm 이동하고 전방 기둥 깊이를28 mm로 조정함. 측면 회전 출력 STL 별도 제공(180×162×196 mm), 5 mm 브림의 가상영역190×172 mm. 구조 FEA 미실시.

## 0.6.0 / Rev F

8인치 저상형(바닥Z=-80), 수평 편심 배치, AP203/AP214·BREP와 FreeCAD 직접가져오기 경로. 외곽212×162×180 mm였음.
